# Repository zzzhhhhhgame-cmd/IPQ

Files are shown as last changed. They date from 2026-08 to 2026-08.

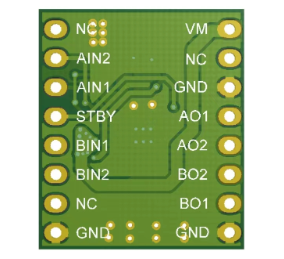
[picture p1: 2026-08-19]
参考资料/D2-1-2F（未焊接）/引脚图.png

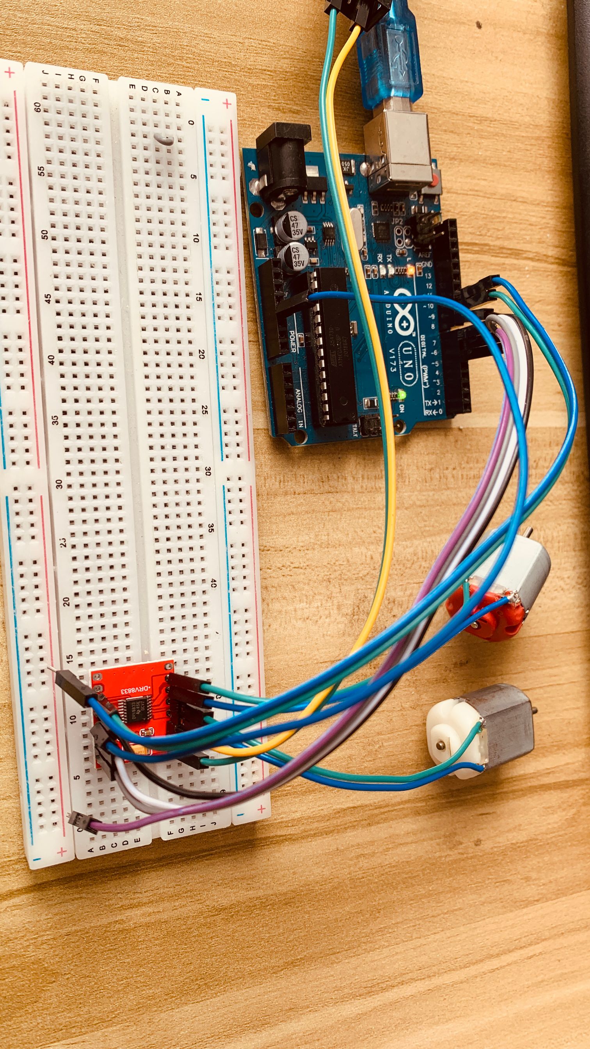
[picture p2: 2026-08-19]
参考资料/D2-1-2F（未焊接）/实物图.png

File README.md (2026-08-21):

# IPQ 项目仓库

**研究课题**：在自建双电机小车上，对比 S 曲线开环运动规划与 PID 闭环控制在**电能消耗**、**任务时间**上的差异，并量化 PID 反馈对**双轮转速差**（直线跑偏）的抑制能力——这是开环控制无法解决的问题。

**硬件平台**：ESP32 DevKit V1 + DRV8833 电机驱动 + JGB37-520B 编码器电机 ×2 + INA226 电压/电流传感器 + IMU（MPU6050 / LSM6DS3 自动识别）+ microSD 模块。

---

## 目录结构

```
IPQ/
├── 工程文件/          # 小车工程：代码、接线、物料清单
│   ├── ipq_robot_test/        # 全系统联合测试程序（.ino + 操作说明）
│   ├── ipq_pid_speed/         # 双轮 PID 速度控制程序（.ino + 教程/说明 + 串口日志）
│   ├── i2c_identify/          # I2C 器件识别小工具（确认 IMU 实际芯片型号）
│   ├── wiring.html            # 接线总图（网页版）
│   ├── wiring-checklist.html  # 逐线接线检查清单（v3.1，与固件引脚一一对应）
│   ├── bom.html               # 物料清单（BOM）
│   └── pcb/                   # 面包板→PCB 载板工程（Gerber/原理图/装配说明，见 pcb/README.md）
│
├── 答辩/              # 项目申请书（Project Proposal Form）及答案草稿
│   ├── PPF draft answers.md              # PPF 各栏目的答案草稿（Markdown，便于复制修改）
│   ├── project proposal form - IPQ draft.docx  # 申请书 Word 草稿（与上一文件内容一致）
│   └── project proposal form(1).docx           # 申请书 Word 版本
│
├── 参考资料/          # 整理性资料：硬件资料、教材、论文总结、实验提取报告及其生成脚本
│   ├── D2-1-2F（未焊接）/               # DRV8833 驱动板产品资料（接线说明、引脚图、真值表、芯片手册、uno 示例代码）
│   ├── PID Controllers (Åström & Hägglund).pdf  # PID 控制经典教材（理论背景）
│   ├── summaries/                    # 5 篇论文的中文总结 PDF（自整理）
│   ├── extracted/                    # 5 篇论文的全文纯文本提取（工作数据）
│   ├── Experiment_Extraction_Report.pdf  # 5 篇论文的实验设计提取报告（自整理）
│   ├── gen_summaries.py              # 生成 summaries/ 的脚本（ReportLab）
│   ├── gen_experiments.py            # 生成 Experiment_Extraction_Report.pdf 的脚本
│   └── _exp_content.py               # 提取报告的正文数据（被 gen_experiments.py 加载）
│
├── 参考文献/          # 研究引用的原始文献
│   └── paper/         # 5 篇原始论文 PDF（括号内为对应总结编号）
│       ├── Control-BLDC-Motor-Speed-using-PID-Controller.pdf            # Mahmud et al., 2020（01）
│       ├── Design_and_implementation_speed_control.pdf                 # Hammoodi et al., 2020（02）
│       ├── FA01_1.pdf                                                  # Meckl et al., 1998（03）
│       ├── Speed_Control_of_DC_Motor_Using_Fuzzy_PI.pdf                # Bansal et al., 2013（04）
│       └── nguyen-et-al-2008-on-algorithms-for-planning-s-curve-motion-profiles.pdf  # Nguyen et al., 2008（05）
│
├── .gitignore
└── .gitattributes
```

---

## 分类说明

### 1. 工程文件（及其说明）

小车本体相关的全部工程内容。三个 Arduino/ESP32 工程：

| 工程 | 用途 |
|---|---|
| `ipq_robot_test` | 全系统联合测试：双电机 + 编码器 + IMU + INA226 + microSD，遥测 10 Hz 记录 |
| `ipq_pid_speed` | 双轮独立 PID 速度控制（含抗积分饱和），附实验教程、使用说明和串口日志（`serial_logger.py` 采集） |
| `i2c_identify` | I2C 总线扫描，识别传感器板上实际焊接的芯片型号 |

接线与物料文档：`wiring*.html` 与 `bom.html`，其中 `wiring-checklist.html` v3.1 与固件引脚定义逐线对应。`pcb/` 为面包板方案的 PCB 载板工程（Python 生成 Gerber，可直接在嘉立创下单；含原理图、预览与装配说明）。

### 2. 答辩

IPQ 项目申请书（Project Proposal Form）的填写材料。`PPF draft answers.md` 是各栏目答案的 Markdown 版，便于编辑和复制；两份 `.docx` 为提交用的 Word 版本。**待填写**：Candidate number（大考 4 位考号）、Candidate name（护照拼音名）。

### 3. 参考资料

围绕文献与硬件做的整理性材料：

- **硬件资料**（`D2-1-2F（未焊接）/`）：所用 DRV8833 驱动板的产品资料（接线说明、引脚图、真值表、芯片手册、uno 示例代码）。
- **教材**：Åström & Hägglund《PID Controllers》，PID 整定理论的背景阅读。
- **论文总结**（`summaries/`）：5 篇核心文献的中文总结 PDF。
- **实验提取报告**（`Experiment_Extraction_Report.pdf`）：从 5 篇论文中提取的自变量/因变量/控制变量等实验设计要素，用于设计自己的实验方案。
- **生成脚本**：`gen_summaries.py` 与 `gen_experiments.py`（加载 `_exp_content.py`）可用 ReportLab 重新生成上述 PDF；`extracted/` 为论文纯文本提取结果。

### 4. 参考文献

研究引用的 5 篇原始论文（`paper/`），编号与 `参考资料/summaries/` 一一对应。申请书中引用的完整文献还包括 Åström & Hägglund 教材（见 `参考资料/`）。

---

## 文档再生成方法

两个生成脚本已改为相对路径，可在任意系统上运行（依赖 `reportlab`；中文字体自动在 Windows / macOS 系统字体中查找，也可将 Noto Sans SC 字体放在脚本同目录）：

```bash
cd 参考资料
pip install reportlab
python gen_summaries.py     # 重新生成 summaries/ 下 5 份总结 PDF
python gen_experiments.py   # 重新生成 Experiment_Extraction_Report.pdf
```

## 工作约定

- 修改任何文件后提交并推送到 `origin/main`。

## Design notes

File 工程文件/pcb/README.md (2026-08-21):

# IPQ 小车模块载板（面包板 → PCB）

把 `wiring v3.3` 的 **42 根杜邦线变成一块 PCB**。板上提供 ESP32 / DRV8833 / GY-521 的排母插座和电池、电机、编码器接线端子；INA226、MP1584、microSD 三个"丝印版本多变"的模块通过标牌插座 + 杜邦线/短线对接（**任意版本都兼容，不会插错**）。固件（`ipq_robot_test` / `ipq_pid_speed`）引脚无需任何改动。

- 板子：**95 × 80 mm，2 层，1.6mm**，底层整板 GND 铺铜（带热焊盘）
- 电气上与面包板版完全一致：逻辑电源在 INA226 之前分支（INA226 只测电机能耗）、STBY 接 3V3、INA226 串联在 电池+ → VM 之间

## 文件说明

| 文件 | 用途 |
|---|---|
| `out/IPQ_CARRIER_V1_gerber.zip` | **嘉立创直接上传的制造文件**（Gerber + 钻孔） |
| `out/schematic.svg` | 电路原理图（浏览器打开） |
| `out/preview_top.png` / `out/preview_bottom.png` | 顶层 / 底层铜预览图 |
| `out/report.txt` | 自动间距检查（DRC-lite）报告，0 错误 |
| `gen_board.py` + `gerblib.py` | 生成器源码（改布局后 `python3 gen_board.py` 重新生成一切） |
| `check_connect.py` | 网络连通性审计（每条网络单一连通分量） |
| `gen_schematic.py` | 原理图生成器 |

## 嘉立创下单步骤

1. 打开 [jlc.com](https://www.jlc.com) → PCB 制造 → **上传 PCB 制造文件**，选 `out/IPQ_CARRIER_V1_gerber.zip`。
2. 参数确认（其余默认）：
   - 层数 **2**，板厚 **1.6mm**，数量 **5**（经济板约 ¥2–10 + 运费）
   - 颜色任意（绿色最便宜/最快），表面处理默认"喷锡（有铅）"，阻焊覆盖过孔：是
   - 系统识别的最小线宽/间距应 ≥ 0.4/0.2mm（本板最小值，满足经济板工艺）
3. 预览核对：上传后在线预览应与 `preview_top.png` 一致（顶层丝印 "IPQ-2026 ROBOT CARRIER v1.0"）。

## ⚠ 下单前必做：两个尺寸核对（拿尺子量你手上的模块）

插座位置按以下尺寸设计，若与你手上的模块不符，**先改 `gen_board.py` 顶部常量再重新生成**：

| 模块 | 设计采用尺寸 | 怎么量 |
|---|---|---|
| ESP32 DevKit V1 30P | 两排孔中心距 **22.86mm**（0.9 英寸，行业标准） | 量板上两排焊孔中心距离 |
| DRV8833 (D2-1-2F) | 2 列 × 8 孔、列内间距 2.54、**两列中心距 10.16mm** | 对照模块丝印逐孔核对：左列 NC·AIN2·AIN1·STBY·BIN1·BIN2·NC·GND，右列 VM·NC·GND·AO1·AO2·BO2·BO1·GND |
| GY-521 | 1×8 孔 @2.54 | 通用 |

> 若 DRV8833 实测列距不是 10.16mm（比如 12.7），只需改 `gen_board.py` 中 `DX_R = 62.16` 一行（= 左列 x + 实测列距），重跑生成器即可，布线已按 2.54 网格自适应大部分调整。

## 载板装配清单（PCB 之外要买的插件）

| 器件 | 数量 | 规格 / 搜索关键词 |
|---|---|---|
| 排母 1×15P 2.54mm | 2 | ESP32 插座（可用 2×15 整条剪开） |
| 排母 1×8P 2.54mm | 3 | DRV8833 ×2 + GY-521 ×1 |
| 排母 1×6P 2.54mm | 1 | microSD 插座 |
| 排母 1×4P 2.54mm | 2 | MP1584 / INA226 逻辑插座 |
| 排母 1×2P 2.54mm | 1 | J9 逻辑电源跳线（配跳线帽） |
| 端子 KF301-2P 5.08mm | 5 | 电池 ×1、电机 ×2、INA226 动力 ×2（用 1×4P 剪或买 2P） |
| 端子 KF3500-4P 3.5mm | 2 | 编码器（左右） |
| 电解电容 100µF/16V | 1 | C1（VM 滤波，5mm 脚距） |
| 瓷片电容 104 (100nF) | 1 | C2（2.54 脚距） |
| 跳线帽 2.54mm | 2 | J9 电源 + JP1 SD-VCC 选择 |
| M3 螺丝/铜柱 | 4 | 固定到车上 |

安装提示：排母建议选 8.5mm 高（普通 8.5mm 即可，模块插入后芯片面朝上）。

## 装配顺序（建议）

1. 焊 C2（瓷片，最矮）→ C1（电解，**长脚为正极朝 VM 一侧**，板上丝印有 + 标记）。
2. 焊全部排母、端子、J9/J P1 跳线座。端子焊缝开口朝板外（插线方向）。
3. 插上 ESP32（USB 朝板上边缘，对照丝印 "USB THIS END"）。
4. **DRV8833 模块先自己焊好 2×8 排针**（模块丝印朝上时：左列对齐载板左列丝印 NC·AIN2·AIN1·STBY·…），再插入排母。
5. GY-521 直接插入 1×8 排母（板上丝印 VCC·GND·SCL·SDA·…）。
6. 三根杜邦线对接 MP1584（**按丝印一一对应**：IN+/IN−/OUT+/OUT−）；四根对接 INA226 逻辑侧（VCC/GND/SDA/SCL）。
7. 动力路径两根粗线（≥20AWG）：
   - `J8 BAT+` 端子同时压接「电池盒红线」+「去 MP1584 的分接线」（与面包板方式 A 相同）
   - `J6 V+IN` → INA226 模块 **VIN+** 端子；INA226 模块 **VIN−** → `J6 V-OUT`
8. microSD 六根杜邦线按丝印对接；JP1 按模块版本把中间焊盘与 3V3 或 5V 焊锡桥接。
9. 电机线接入 J13/J14（M+/M−），编码器线接入 J2/J3（板上丝印 A·B·GND·3V3）。

## 上电检查（沿用面包板版清单）

- 万用表量 J8 空载：BAT+ 对 GND 应不通；接电池后 VM 端子（J6 V-OUT 侧）对 GND ≈ 电池电压（经 INA226）
- J9 插跳线帽 = 逻辑上电；拔掉 = 逻辑断电（拔电池才是完全断电）
- 先不接电机，I²C 扫描应出 **0x40 (INA226)** 和 **0x68 (MPU6050)**
- 低 PWM（30%）试转，方向不对就对调 AO1/AO2（或 BO1/BO2）两根电机线
- 烧录失败：拔下 microSD 模块再烧（GPIO2 是启动脚，与面包板版相同）

## 已知取舍

- microSD / INA226 / MP1584 采用杜邦线对接而非插座直插：这三个模块市面上丝印顺序五花八门，直插底板一旦做错就整板报废；标牌对接对任意版本零风险，也便于烧录时拔 SD。
- 逻辑电源开关（J9 跳线）只控制 MP1584 输入（≤0.5A）；电机主回路不串开关（小开关扛不住堵转电流），完全断电请拔电池端子。

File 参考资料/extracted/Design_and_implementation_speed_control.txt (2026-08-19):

International Journal of Power Electronics and Drive System (IJPEDS) 
Vol. 11, No. 1, March 2020, pp. 127~134 
ISSN: 2088-8694, DOI: 10.11591/ijpeds.v11.i1.pp127-134 
     127 

Journal homepage: http://ijpeds.iaescore.com 
Design and implementation speed control system of DC Motor 
based on PID control and Matlab Simulink 

Salman Jasim Hammoodi1, Kareem Sayegh Flayyih2, Ahmed Refaat Hamad3 
1 Department of Machines Technology, Middle Technical University, Iraq 
2 Department of Electronic Technology, Southern technical University, Iraq 
3 Department of Electrical Technology, Middle Technical University, Iraq 

Article Info 
 
ABSTRACT 
Article history: 
Received May 9, 2019 
Revised Jul 22, 2019 
Accepted Aug 4, 2019 

In this paper, we first write a description of the operation of DC motors 
taking into account which parameters the speed depends on thereof. The PID 
(Proportional-Integral-Derivative) controllers are then briefly described, and 
then applied to the motor speed control already described, that is, as an 
electronic controller (PID), which is often referred to as a DC motor. The 
closed loop speed control of a Brush DC motor is developed applying the 
well-known PID control algorithm. The objective of this work is to designed 
and simulate a new control system to keep the speed of the DC motor 
constant before variations of the load (disturbances), automatically 
depending to the PID controller. The system was designed and 
implementation by using MATLAB/SIMULINK and DC motor. 
Keywords: 
DC Motor 
MATLAB/SIMULIK 
PID 
PWM 
Speed control 
This is an open access article under the CC BY-SA license. 
 
Corresponding Author: 
Salman Hammoodi,  
Department of Machines Technology, 
Institute of Technology Baghdad, Middle Technical University, 
Al-Za’franiya, 10074 Baghdad, Iraq 
Email: salmanhammoodi66@gmail.com 

1. 
INTRODUCTION 
At present, most of the motors in the industry are handled directly from the electrical distribution 
lines, whether they are DC or AC motors. Because of this, the behaviour of the motor depends on the nature 
of the load coupled to the axis of the machine [1-5]. In the case of a light load the motor develops a relatively 
high speed and a low torque because it is the load requirement. On the contrary, if a heavy or difficult to 
move load is available, the motor will move at a lower speed and deliver more torque as a higher load 
demands it [4-9]. 
As can be seen by directly connecting the motor to the AC or DC electrical network, its behaviour is 
defined and it will remain unchanged for a certain fixed voltage in the power supply line. However, in a large 
part of the industrial sector, there are processes in which the management of the operating characteristics of 
said machines is required, which is why parameter control devices such as speed and frequency variations are 
used. In the case of AC motors, these devices are commonly used and have a relatively low cost, however, 
when working with DC motors the variable speed drives have an excessively high cost which makes them 
little accessible to many industries that require its use [6-12]. 
In this paper to design and implementation speed control system of DC Motor based on PID control 
and Matlab Simulink, the motor is divided into two main parts the electrical part of the armature and the 
mechanical part [11, 12]. The armature is modelled as a circuit with resistance R connected in series to a 
conductor L, a source of voltage V and constant Kb of force against electromotive in the armature. The 
      
  
 
       ISSN: 2088-8694 
 Int J Pow Elec & Dri Syst Vol. 11, No. 1, Mar 2020 :  127 – 134 
128
mechanical part of the motor is the rotor which, when in motion, has a moment of inertia J, a Torque T, a 
viscous friction coefficient b, a position θ and an angular velocity bθ = ω [4,7,10,11-12]. 
The PID controller is responsible for correcting the error it receives from the difference of the input 
signal and the output signal of the tachometer, the corrected error enters an amplification stage before 
entering the plant. In this paper the development of a speed and direction motor for an autonomous race robot 
is presented. Both controls use the PID control algorithm [13, 15-20]. 
The paper aims to provide a solution to the difficult access that economic conditions have for these 
automation technologies, developing an own speed control system for any DC motor that requires it, 
economically viable and applicable to any type of machine, of easy use and implementation in all types of 
industrial processes[19-25]. 

2. 
THE BASICS OF DC MOTORS 
The history of the development of the construction of electric machines began in 1831 with the 
discovery of Faraday's law until the middle of the eighth decade of the last century. The DC motors are 
machines that convert electrical energy into mechanical energy, causing a rotary movement. There were 
several reasons for the prolonged popularity of dc motors. One was that DC power systems are common even 
in cars, trucks and airplanes. When a vehicle has a DC power system, it makes sense to use DC motors. DC 
motors were also applied when wide variations in speed were required. Before the widespread use of 
electronic power rectifier inverters, dc motors were not matched in speed control applications. Even if there 
were no dc power source, the solid-state rectifiers and the trimmer circuits were used to create the necessary 
power; dc motors were used to provide the desired speed control (induction motors with groups of solid-state 
controllers are now preferred for most speed control applications.) However, there are still applications where 
DC motors)[6-9]. 
The dc motors are driven by a dc power source. Unless otherwise specified, it is assumed that the 
input voltage is constant, since this assumption simplifies the analysis of the motors and the comparison 
between the different types of them. There are five types of general purpose DC motors: 
 
Independent excitation direct current motor. 
 
Direct current motor in derivation. 
 
Permanent magnet direct current motor. 
 
Direct current motor in series. 
 
Composite direct current motor. 
The Figure 1 show the full equivalent circuit of the dc motor. The equivalent circuit in Figure 1 is 
similar to the generator circuit only the current directions are different. The operation equations are, (1) is 
present the Armature voltage equation [11-12].  

Figure 1. Full equivalent circuit of DC motor 

𝑉ௗ௖ൌ𝐸௔௠൅𝐼௔௠𝑅௔൅𝑉௕௥௨௦௛ 
(1) 
 
The induced motor voltage and motor speed vs angular frequency of the motor is present in (2). The 
combination is present in (3) and the output power and torque are present in (4). 
 
𝐸௔௠ൌ𝐾௠𝐼௙𝜔 
 
𝜔ൌ2𝜋𝑛௠ 
(2) 
𝐾௠𝐼௙𝜔ൌ𝐸௔௠ൌ𝑉ௗ௖െ𝐼௔௠𝑅௠ 
(3) 
𝑃௢௨௧ൌ𝐸௔௠𝐼௔௠  
Int J Pow Elec & Dri Syst 
ISSN: 2088-8694 
 
 
Design and implementation speed control system of DC Motor based on PID ... (Salman Jasim Hammoodi) 
129
𝑇ൌ
௉೚ೠ೟
ఠൌ𝐾௠𝐼௔௠𝐼௙ 
(4) 

3. 
THE EXPLANATION OF PID CONTROLLER SYSTEM 
3.1. The control systems 
Automatic control is of vital importance in the world of engineering. In addition to being essential in 
robotic systems or modern manufacturing processes, among others applications, has become essential in 
industrial operations such as pressure control, temperature, humidity and viscosity, and flow in the 
processing industries. Figure 2 shows a generic block diagram of a control system, in the Laplace domain. 

Figure 2. The block diagram of a control system 

Typically, the feedback contains a sensor or transducer element that measures a physical parameter, 
such as speed or temperature, and converts it into a voltage or current. 
The basic function of a controller is to compare the real value of the output of a plant c(t), with the 
reference input r(t) (desired value), determine the error e(t), and produce a control signal that will reduce the 
error to a value close to zero. 
Figure 3 present the specifications for a control problem are often given in the time domain,  
and usually include a certain transient response and an error in state stationary, for a specific entry as is 
usually a step. 

Figure 3. The specifications for a control problem 

One way to achieve this is by placing a transfer driver Gc (s), in the control loop, as shown in the 
Figure 3. The error signal E (s) is the input to the controller, and U (s) is the output of the same and at the 
same time the input to the plant, and the purpose of the controller is to make the output of the system follow 
the input. In Figure 4 we observe the different types of response according to the controller that is used. 

  
 
       ISSN: 2088-8694 
 Int J Pow Elec & Dri Syst Vol. 11, No. 1, Mar 2020 :  127 – 134 
130

Figure 4. Response to the step of a closed-loop feedback system given by: (a) Controller P (b) Controller PD 
(c) Controller PID 

3.2. The PID controllers method 
error is changing with respect to time. In this way, the controller can estimate future values of the 
error signal and compensate accordingly. It should be taken into account that even if the error is constant and 
the derivative term does not contribute, if it is variant in time this term can be used to reduce the offset called 
steady-state error. Another problem associated with the PD is that it works like a high-pass filter. Therefore, 
the PD controller amplifies the high frequency noise, which reduces the stability of the total system. 
To eliminate the steady state error, an integral term is added. That term it gives the PID controller 
the ability to remember the past, also allowing an output non-zero for a null entry. So this controller allows to 
have a status error stationary equal to zero. In return, the integrator adds a pole in the function of closed loop, 
with which the stability of the system declines. From the above, the PID is an excellent controller. The 
transfer function is given in (5)[12-18]: 
 
𝐺௖ሺ𝑠ሻൌ𝐾௣൅𝐾ௗ. 𝑆൅
௄೔
ௌ 
(5) 
 
It should be clarified that if a mathematical model of the plant can be deduced, it is possible apply 
several techniques to determine the controller parameters, which comply with the transient and steady state 
specifications of the closed loop system. However, if the plant is so complicated that you cannot easily obtain 
your mathematical model, the analytical design model of the PID controller is possible. Then you have to 
resort to experimental procedures for the design of this type of controller. The process of select the 
parameters of the controller so that it meets the specifications of operation is known as tuning or tuning the 
controller. Ziegler and Nichols suggested rules for tuning PID controllers, that is, setting the values of Kp, 
Kd and Ki[11,16]. 
 
3.3. Types of PID controllers  
for PIDs The transfer functions for the different types of PID drivers are[20-25]: 
a. 
PID not interacting or ideal form : is present in (6). 
 
𝐺௖ሺ𝑝ሻൌ𝐾௖. ቀ1 ൅
ଵ
்೔൅
ଵା்೏.௣
ଵାఈ.்೏.௣ቁ 
(6) 
 
b. 
Interactive PID or series form : is present in (7). 
 
𝐺௖. ሺ𝑝ሻൌ𝐾௖. ቀ1 ൅
ଵ
௄೔.௣ቁ. ቀ
ଵା்೏
ଵାఈ.்೏.௣ቁ 
(7) 
 
c. 
PID parallel form : is present in (8). 
 
Int J Pow Elec & Dri Syst 
ISSN: 2088-8694 
 
 
Design and implementation speed control system of DC Motor based on PID ... (Salman Jasim Hammoodi) 
131
𝐺௖ሺ𝑝ሻൌ𝐾௣൅
௄೔
௣൅
௄೏.௣
ଵାఈ.்೏.௣ 
(8) 
 
d. 
PID industrial form : is present in (9). 
 
𝑢ሺ𝑡ሻൌ𝐾௖. ቀ1 ൅
ଵ
்೏.௣ቁ. ቀ𝑟ሺ𝑡ሻെ
ଵା்೏.௣
ଵାఈ.்೏.௣. 𝑦ሺ𝑡ሻቁ 
(9) 

4. 
SIMULATION RESULTS AND DESCTIONS 
Figure 5 shows the final MATLAB/SIMULINK speed control circuit separately excited dc motor 
using chopper transistor circuit. MATLAB/SIMULINK toolbox is used in this paper to model the full 
system, it consists of DC motor fed by a DC source voltage through a chopper transistor circuit. A single of 
GTO-1 thyristor with its full control circuit and a free wheeling diode form the chopper circuit. The GTO-1 is 
a switch modeled. The switch block model has three terminals: the middle terminal is a controls which of the 
two other terminals is routed to the output. The control input signal is one, DC V is leading to the output 
voltage, on the other hand, the control input singals is zero, a zero will be leading to the output. 

Figure 5. The final simulation circuit of the speed control motor based on PID control 

The DC motor drives system with a mechanical load characterized by inertia (J), friction coefficient 
(B), and torq of the load (TL). The control circuit of the DC motor system consists of a speed control loop. A 
proportional-integral-Drivetive (PID) controlled the speed of the control loop senses the actual speed of the 
DC motor, and compares the mesurring speed with the reference speed (constant value) to determine the 
reference armature current will be required by the DC motor. One may notice that any difference in actual 
speed is a measure of the current of the motor required by the engine. 
The simulation results of the full system are present on Figure 6 to Figure 9. Figure 6 present the 
simulation results of rated speed (wr) related to the reference speed, in this figure we can see the fast 
response of the PID control system of the system.  

  
 
       ISSN: 2088-8694 
 Int J Pow Elec & Dri Syst Vol. 11, No. 1, Mar 2020 :  127 – 134 
132

Figure 6. Simulation results of rated speed (wr) related to the reference speed 

The load torque (TL) in Figure 7 and the armature current (A) of the DC motoe is presented in the 
Figure 8 of the DC motor is presented the same fast response of the PID control system. Finaly the PWM 
signals of the thyristor (GTO-1) is presented in the Figure 9.  
 
Note: The parameter of the PID are (P=4, I=0.01 and D=0.5. 

Figure 7. The load torque (TL) of the DC motoe 
Int J Pow Elec & Dri Syst 
ISSN: 2088-8694 
 
 
Design and implementation speed control system of DC Motor based on PID ... (Salman Jasim Hammoodi) 
133

Figure 8. The armature current (A) of the DC motoe 

Figure 9. The PWM signals of the thyristor (GTO-1) 

5. 
CONCLUSION 
The first point discussed in this work was the description of the operation of a DC motor, where the 
different aspects related to its operation were analysed, and the parameters that influence the speed control of 
them. Then, made the operation of the PID controllers system, and their application to the control of the 
speed of a DC motor. It is important to consider here that the effect on the dynamic behaviour of a control 
loop is directly related to the type of controller used, PID in our specific case, and its operation, either as a 
servomechanism or as a regulatory system. But it must also be taken into account that the equations used by 
the manufacturers to carry out their PID controllers are not all the same. 
The differences that exist between the equations used by the manufacturers to represent the PID 
algorithm in their loop controllers, direct digital control programs and other equipment, make it indispensable 
to know in order to be able to calculate the required parameters thereof in an appropriate manner and achieve 
the desired dynamic behaviour of the control loop. The foregoing is fundamentally important when replacing 
one controller with another, especially if the new one is from another manufacturer. 
The results that have been presented and the methodology that has been proposed represent an 
important contribution in the field of experimental modelling of systems for obtaining models of the 
dynamics of unknown systems. 
      
  
 
       ISSN: 2088-8694 
 Int J Pow Elec & Dri Syst Vol. 11, No. 1, Mar 2020 :  127 – 134 
134
REFERENCES 
[1] 
A. J. Humaidi and I. Kasim Ibraheem, “Speed Control of Permanent Magnet DC Motor with Friction and 
Measurement Noise Using Novel Nonlinear Extended State Observer-Based Anti-Disturbance Control,” Energies, 
vol. 12, no. 9, p. 1651, 2019. 
[2] 
X. Yao, J. Zhao, G. Lu, H. Lin, and J. Wang, “Commutation Error Compensation Strategy for Sensorless Brushless 
DC Motors,” Energies, vol. 12, no. 2, p. 203, 2019. 
[3] 
J. Hong, S. Wang, Y. Sun, and H. Cao, “An effective method with copper ring for vibration reduction in permanent 
magnet brush DC motors,” IEEE Trans. Magn., vol. 54, no. 11, pp. 1–5, 2018. 
[4] 
L. Li and D. Jia, “Research on Air conditioning system of subway station based on fuzzy PID control,” Proc. - 
2017 4th Int. Conf. Inf. Sci. Control Eng. ICISCE 2017, pp. 1131–1134, 2017. 
[5] 
E. Guerrero, J. Linares, E. Guzmán, H. Sira, G. Guerrero, and A. Martínez, “DC Motor Speed Control through 
Parallel DC/DC Buck Converters,” IEEE Lat. Am. Trans., vol. 15, no. 5, 2017. 
[6] 
P. Alaeinovin and J. Jatskevich, “Filtering of hall-sensor signals for improved operation of brushless DC motors,” 
IEEE Trans. Energy Convers., vol. 27, no. 2, pp. 547–549, 2012. 
[7] 
X. Changbo, L. Congcong, B. Zhenfu, and Z. Chengjin, “PID self-tuning immune fuzzy control of steam 
temperature control system in fossil-fired power plant,” Proc. World Congr. Intell. Control Autom., vol. 1,  
pp. 3973–3977, 2006. 
[8] 
N. Kasa and H. Watanabe, “A mechanical sensorless control system for salient-pole brushless DC motor with 
autocalibration of estimated position angles,” IEEE Trans. Ind. Electron., vol. 47, no. 2, pp. 389–395, 2000. 
[9] 
Y. Mandel and G. Weiss, “Reduction of torque ripple in brushless DC motor drives,” IFAC Proc., vol. 6, no. 1,  
pp. 84–89, 2009. 
[10] I. Alhamrouni, M. A. Hairullah, N. S. Omar, M. Salem, A. Jusoh, and T. Sutikno, “Modelling and design of PID 
controller for voltage control of AC hybrid micro-grid,” International Journal of Power Electronics and Drive 
System (IJPEDS), vol. 10, no. 1, pp. 151–159, 2019. 
[11] M. A. Ibrahim, A. K. Mahmood, and N. S. Sultan, “Optimal PID controller of a brushless DC motor using  
genetic algorithm,” International Journal of Power Electronics and Drive System (IJPEDS), vol. 10, no. 2,  
pp. 822–830, 2019. 
[12] N. N. Baharudin and S. M. Ayob, “Brushless DC motor speed control using single input fuzzy PI controller,” 
International Journal of Power Electronics and Drive System (IJPEDS), vol. 9, no. 4, pp. 1952–1966, 2018. 
[13] Y. Tarmizi, A. Jidin, K. A. Karim, and T. Sutikno, “A simple constant switching frequency of direct torque control 
of brushless DC motor,” International Journal of Power Electronics and Drive System (IJPEDS), vol. 10, no. 1,  
pp. 10–18, 2019. 
[14] M. Dasari, A. Srinivasula Reddy, and M. Vijaya Kumar, “GA-ANFIS PID compensated model reference adaptive 
control for BLDC motor,” International Journal of Power Electronics and Drive System (IJPEDS), vol. 10, no. 1, 
pp. 265–276, 2019. 
[15] Mohannad Jabbar Mnati, “Position Control for flexible Joint Maipulator using Artificaial Neutral Network”, 
University of Technology, Department Of Electrical & Electrionics Engineering, Baghdad, Iraq, 2005. 
[16] P. Bhaskara Prasad, M. Padma Lalitha, and B. Sarvesh, “Fractional order PID controlled cascaded re-boost seven 
level inverter fed induction motor system with enhanced response,” International Journal of Power Electronics and 
Drive System (IJPEDS), vol. 9, no. 4, pp. 1784–1791, 2018. 
[17] R. Meena Devi and L. Premalatha, “Soft computing technique of bridgeless SEPIC converter for PMBLDC motor 
drive,” International Journal of Power Electronics and Drive System (IJPEDS), vol. 9, no. 4, pp. 1503–1509, 2018. 
[18] A. Rincón, F. Angulo, and F. Hoyos, “Controlling a DC Motor through Lypaunov-like Functions and SAB 
Technique,” International Journal of Electrical and Computer Engineering (IJECE), vol. 8, no. 4, p. 2180, 2019. 
[19] M. J. Mnati, D. V. Bozalakov, and A. Van den Bossche, “PID Control of a Three Phase Photovoltaic Inverter Tied 
to a Grid Based on a 120-Degree Bus Clamp PWM,” IFAC-PapersOnLine, vol. 51, no. 4, pp. 388–393, 2018.  
[20] A. Faruq, M. F. N. Shah, and S. S. Abdullah, “Multi-objective optimization of PID controller using pareto-based 
surrogate modeling algorithm for MIMO evaporator system,” International Journal of Electrical and Computer 
Engineering (IJECE), vol. 8, no. 1, pp. 556–565, 2018. 
[21] A. Prayitno, V. Indrawati, and I. I. Trusulaw, “Fuzzy gain scheduling PID control for position of the AR. Drone,” 
International Journal of Electrical and Computer Engineering (IJECE), vol. 8, no. 4, pp. 1939–1946, 2018. 
[22] H. Sun, M. J. Mnati, M. Nabil Ibrahim, and A. Van Den Bossche, “A Tuning Method for the Derivative Filter in 
PID Controller with Delay Time,” Proc. 2018 9th Int. Conf. Mech. Aerosp. Eng. ICMAE 2018, pp. 574–578, 2018. 
[23] H. Sun, M. N. Ibrahim, M. Jabbar Mnati, and A. Van Den Bossche, “A Tuning Method for PI Controller for an 
Integrating System with Time Delay,” Proc. 2018 9th Int. Conf. Mech. Aerosp. Eng. ICMAE 2018, pp. 410–414, 
2018. 
[24] M. Yaich and M. Ghariani, “A novel technique for tuning PI-controller in switched reluctance motor drive for 
transportation systems,” International Journal of Electrical and Computer Engineering (IJECE), vol. 8, no. 6, pp. 
4272–4281, 2018.  
[25] M. A. Shamseldin, M. Sallam, A. M. Bassiuny, and A. M. Abdel Ghany, “A novel self-tuning fractional order PID 
control based on optimal model reference adaptive system,” International Journal of Power Electronics and Drive 
System (IJPEDS), vol. 10, no. 1, pp. 230–241, 2018.

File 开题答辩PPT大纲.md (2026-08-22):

# 开题答辩 PPT 大纲与讲稿（7–8 分钟，纯英文）

> 配套文件：`project proposal form - IPQ draft.docx` / `PPF draft answers.md`
> **成品幻灯片：`IPQ开题答辩.pptx`（12 页，16:9）**——本大纲即其逐页内容与讲稿。
> 用法：每页给出【幻灯片上放什么】（英文要点）和【讲什么】（英文讲稿，含时长）。
> 讲稿全文约 1150 词 ≈ 7 分半（140 词/分钟）。幻灯片只放要点，句子留给嘴说。
> 待替换项：第 1 页 `[Your Name]`；第 3、9 页的图片占位框（小车照片、CSV 曲线截图）。

## 总览

| # | 幻灯片 | 部分 | 时长 |
|---|---|---|---|
| 1 | Title | — | 0:20 |
| 2 | Outline | — | 0:15 |
| 3 | The Problem I Met | 1 背景与动机 | 0:50 |
| 4 | Two Ways to Command a Motor | 1 背景与动机 | 1:00 |
| 5 | Research Gap & Research Question | 1 背景与动机 | 0:45 |
| 6 | Test Platform & Measurement | 2 实验设计 | 0:45 |
| 7 | Variables & Experimental Protocol | 2 实验设计 | 1:00 |
| 8 | Metrics & Hypotheses | 2 实验设计 | 0:45 |
| 9 | Feasibility: Platform & Data Pipeline | 3 可行性 | 0:40 |
| 10 | Feasibility: Skills, Risks & Backups | 3 可行性 | 0:40 |
| 11 | Timeline (Aug 2026 – Apr 2027) | 4 时间规划 | 0:45 |
| 12 | Summary & Expected Contribution | — | 0:30 |

**合计 ≈ 7:35**（留 20–30 秒缓冲）

---

## Slide 1 — Title（0:20）

**幻灯片内容：**
- S-curve vs. PID: Energy, Time and Differential Suppression for a Two-Motor Robot Car
- 一行小字放研究问题缩写版：*Which control strategy moves my robot car faster and cheaper — and which one keeps it straight?*
- Name / Centre CN213 Shanghai Guanghua College / IPQ 06/27 / Date

**讲稿：**
> Good afternoon everyone. My IPQ project compares two classic ways of controlling robot motors — S-curve motion profiling and PID feedback — on a robot car I built myself. I will measure which one completes a movement using less energy and less time, and which one can keep the car driving straight. Let me start with why I chose this topic.

## Slide 2 — Outline（0:15）

**幻灯片内容：**
- 1 Background & Motivation
- 2 Experimental Design
- 3 Feasibility
- 4 Timeline

**讲稿：**
> My presentation has four parts: the background and motivation, the experimental design, the feasibility, and my timeline from now until submission next April.

## Slide 3 — The Problem I Met（0:50）

**幻灯片内容：**
- Built a two-motor robot car (ESP32 + encoder motors)
- Observation 1: motors = biggest power consumer → battery drains fast, much energy wasted
- Observation 2: same PWM ⇒ two wheels differ by ~5% in speed → car drifts off a straight line
- Question raised: does *how* we command the motors change energy cost and accuracy?

**视觉建议：** 小车照片 + 两张遥测截图（rpmL vs rpmR 曲线分叉的那段）

**讲稿：**
> My interest came from building and testing this car. The first thing I noticed is that the motors are by far the biggest power consumers on the car — they drain the battery quickly, and a lot of the energy seems wasted rather than turned into motion. The second observation is on this plot: when both motors receive exactly the same PWM command, the two wheels still run at different speeds — about five percent apart, measured by the wheel encoders. That five percent comes from small manufacturing differences between the two motors, and it makes the car slowly curve off a straight line. So I started asking: does the way we command the motors change how much energy a movement costs, and how accurately the car moves?

## Slide 4 — Two Ways to Command a Motor（1:00）

**幻灯片内容：**
- S-curve motion profiling (open loop)
  - Speed follows a smooth, jerk-limited S-shaped reference
  - Standard in CNC / industrial robots; limits vibration & stress
  - (Nguyen et al. 2008; Meckl et al. 1998)
- PID feedback control (closed loop)
  - Controller corrects PWM continuously from measured speed error
  - Most widely used control algorithm in industry
  - (Åström & Hägglund; Mahmud et al. 2020; Hammoodi et al. 2020)
- Key structural difference: **open loop sees nothing; closed loop corrects**

**视觉建议：** 左右对比框图：左边 S 曲线→PWM→电机（无回箭头），右边编码器→PID→PWM→电机（有反馈回路）

**讲稿：**
> In the literature there are two mainstream answers to "how should a robot command its motors". The first is S-curve motion profiling. The speed reference follows a smooth, S-shaped curve that limits jerk. This is the standard in CNC machines and industrial robots, because it reduces vibration and mechanical stress. The second is PID feedback control, the most widely used control algorithm in industry: the controller reads the actual wheel speed from the encoders and continuously corrects the motor input to reduce the error. The structural difference is crucial: an S-curve profile is open-loop — however beautifully it is planned, it cannot see what the motors actually do. PID is closed-loop — it measures and corrects. In theory, feedback should be able to cancel the five-percent mismatch between my two motors, and no open-loop profile can.

## Slide 5 — Research Gap & Research Question（0:45）

**幻灯片内容：**
- Gap: most comparisons are **simulation-based, single idealised motor**
  - no mismatched-motor problem, no battery, no energy data
- Open questions on real, low-cost hardware:
  1. Which strategy completes a speed-change task with **less energy**?
  2. Which is **faster** to settle at the target speed?
  3. How much can **only PID** suppress the wheel-speed differential?
- **Research question** (highlight box):
  *How do S-curve open-loop profiling and PID closed-loop control compare in electrical energy and task time on a two-motor robot car, and to what extent can PID additionally suppress the wheel-speed difference that open-loop control cannot solve?*

**讲稿：**
> Here is the gap. Almost all the comparisons I found are simulations with a single idealised motor. In simulation the two motors are perfectly matched and power is free, so neither of my real problems exists. On real, battery-powered hardware, three questions stay open: which strategy uses less energy, which one settles faster, and how much wheel-speed differential can feedback alone remove? That gives my research question: I will compare S-curve and PID on the same car in energy and time, and quantify the differential suppression that only PID can provide.

## Slide 6 — Test Platform & Measurement（0:45）

**幻灯片内容：**
- ESP32 + 2 × JGB37-520B encoder motors (330 counts/rev) + DRV8833 driver
- Sensors: INA226 (voltage / current / power) · MPU6050 gyroscope (yaw rate)
- Firmware (already running): dual-wheel PID @100 ms, anti-windup, optional feed-forward
- Telemetry logged at 10 Hz to CSV: target, rpmL, rpmR, PWM, gyrZ, V, I, P
- To add: on-board **S-curve reference generator** for the open-loop mode

**视觉建议：** 平台框图或实物接线图 + CSV 列名截图

**讲稿：**
> This is my test platform, already built and working. An ESP32 controls two geared DC motors with encoders through a motor driver. Two sensing systems make the comparison measurable: an INA226 power sensor samples the electrical voltage, current and power, and a gyroscope measures the car's yaw rate — an independent check of whether the car is turning. The firmware already implements dual-wheel PID with anti-windup, and logs every variable — target speed, both wheel speeds, PWM, yaw rate, voltage, current, power — at ten hertz to a CSV file. The one thing I still need to add is an on-board S-curve reference generator, so the same car can run both strategies.

## Slide 7 — Variables & Experimental Protocol（1:00）

**幻灯片内容：**
- Independent variable: control strategy (S-curve open-loop vs. tuned PID)
- Dependent variables: **energy per task (J) · settling time (s)** · wheel-speed difference (rpmL−rpmR) · yaw rate
- Controlled: same car, surface, battery voltage window, target speeds, routine; ≥3 repeats per condition
- Experiments:
  - **A** Same speed-change task under both strategies → energy & time
  - **B** Step response → dynamics
  - **C** One-factor-at-a-time PID tuning (Kp, Ki, Kd, FF) → fair tuning
  - **D** Identical S-curve commands vs. per-wheel PID → differential suppression
  - **E** Robustness across target speeds (15 / 45 / 90 rpm)
- Extension: PID tracking an S-curve reference (combined strategy)

**讲稿：**
> The design is a controlled experiment. The independent variable is the control strategy. The main dependent variables are energy per movement and settling time, plus the wheel-speed difference and yaw rate. Everything else is controlled: the same car, the same surface, the same battery voltage window, and each condition is repeated at least three times. Five experiments: A runs the identical speed-change task under both strategies and compares energy and time. B measures the step response. C tunes the PID gains one factor at a time — this is important for fairness, so PID is properly tuned, not misrepresented. D is the unique-capability test: identical S-curve commands to both wheels versus independent PID on each wheel, measuring how much feedback removes the differential. E repeats the comparison at different target speeds. If time allows, I will also test a combined strategy: PID tracking an S-curve reference — the best of both worlds.

## Slide 8 — Metrics & Hypotheses（0:45）

**幻灯片内容：**
- Energy: integrate measured power over task time, E = Σ P·Δt (INA226 @10 Hz)
- Settling time: from command until speed stays within ±5% of target
- Analysis: mean ± SD over ≥3 repeats, plots in Python/Excel
- Hypotheses:
  - H1: PID settles **faster** but may overshoot; S-curve is smooth by construction
  - H2: energy outcome is genuinely **open** — that is why it must be measured
  - H3: PID drives rpmL−rpmR → ~0; open-loop S-curve leaves ~5% → drift

**讲稿：**
> How do I judge the winner? Energy is the time integral of the measured electrical power. Settling time runs from the command until the wheel speed stays within a five-percent band of the target. Three hypotheses. First, PID should settle faster, because an S-curve deliberately stretches the acceleration, but PID may overshoot. Second — and this is the honest part — I do not know which one uses less energy; that is exactly why the experiment is worth doing. Third, PID should push the wheel-speed difference close to zero, while the open-loop S-curve leaves the five-percent difference and the car keeps drifting. Any result here is informative.

## Slide 9 — Feasibility: Platform & Data Pipeline（0:40）

**幻灯片内容：**
- Hardware: **built, wired and running** — wiring checklist v3.3 tested
- Firmware: PID, telemetry, CSV logging **already produce data** (sample on the right)
- Remaining build work: one S-curve generator function (weeks, not months)
- Low cost, common components → easy to repair / replace
- Supervisor support for experimental design

**视觉建议：** 一张已经跑出来的 CSV 曲线截图（证明数据管线可用）

**讲稿：**
> Is this feasible? The car is already built and wired, following a tested wiring checklist. The firmware already produces exactly the kind of data I need — this plot on the right came out of a real test run last week. The only engineering work left is one S-curve generator function, which is a matter of weeks, not months. All components are cheap and common, so anything that breaks can be replaced quickly, and my supervisor reviews the experimental design with me.

## Slide 10 — Feasibility: Skills, Risks & Backups（0:40）

**幻灯片内容：**
- Skills in hand: Arduino/ESP32 programming · Python data logging (pyserial, pandas) · PID theory from Åström & Hägglund
- Risk → Mitigation:
  - INA226 sensor drops out → auto-reconnect in firmware + multimeter cross-check
  - Battery voltage drifts → fixed voltage window per session + voltage logging
  - Quantisation noise at short sampling → 100 ms period, low-pass filter, 3+ repeats
  - Schedule slip → 6-week buffer before submission
- Ethics & safety: low voltage (≤9 V), bench-tested, wheels off ground first

**讲稿：**
> On skills: I already write the firmware, the Python logger and the analysis myself, and the PID theory is covered by the literature. Key risks and my mitigations: if the power sensor drops out, the firmware reconnects automatically and I can cross-check with a multimeter. If the battery voltage drifts, I test within a fixed voltage window and log voltage with every sample. Encoder noise is handled by the 100-millisecond sampling period, a low-pass filter and repeated trials. And the timeline carries a six-week buffer. Safety is simple: everything runs below nine volts, and new behaviours are always bench-tested with the wheels off the ground first.

## Slide 11 — Timeline（0:45）

**幻灯片内容（表格或甘特图）：**

| Phase | Time | Deliverable |
|---|---|---|
| S-curve generator + pilot tests | Aug–mid Sep 2026 | tested open-loop mode |
| Main experiments A–E + repeats | mid Sep–Nov 2026 | complete CSV dataset |
| Extension (combined strategy) | Nov–Dec 2026 | extra dataset |
| Data analysis + literature write-up | Dec 2026–Jan 2027 | figures, draft review section |
| Report writing | Jan–Feb 2027 | first full draft |
| Revision + supervisor review | Mar 2027 | second draft |
| Buffer + proofreading + submission | Apr 2027 | final report (06/27 series) |

**讲稿：**
> Here is my plan from now to submission. By mid-September I will finish the S-curve generator and pilot tests. The main experiments with repeats run through November, and December gives room for the combined-strategy extension. January is for analysis and the literature write-up, February and March for drafting and revising the report with my supervisor's feedback, and April is buffer, proofreading and submission. Every phase ends with a concrete deliverable, so slippage is visible early.

## Slide 12 — Summary & Expected Contribution（0:30）

**幻灯片内容：**
- Same car, same task, two strategies — measured, not assumed
- Outcomes: energy vs. time trade-off **+** quantified differential suppression
- Deliverable: evidence-based guidance for battery-powered robots; open dataset
- Thank you — Questions?

**讲稿：**
> To summarise: on one car, under identical conditions, I will measure — not assume — the energy and time trade-off between S-curve planning and PID feedback, and quantify the one thing only feedback can do: keeping two mismatched motors running at the same speed. The result is evidence-based guidance for anyone building battery-powered robots. Thank you — I am happy to take questions.

---

## 讲述小贴士

- 数字要说得出处：5% 差速、10 Hz、100 ms、330 counts/rev、±5% 稳定带——都来自你的真实系统，被追问时用 Slide 6/8 的数据回答。
- 全场只讲一个故事：“我造了车 → 车有两个毛病（耗电、跑偏）→ 两种经典方案各管一半 → 我用同一辆车量化谁换来什么”。
- 时间控制：Slide 7 最容易超时，超了就砍 C（调参）的展开描述，只念加粗部分。

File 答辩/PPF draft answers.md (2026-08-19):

# IPQ Project Proposal Form — 答案草稿

> 与 `project proposal form - IPQ draft.docx` 内容一致，方便复制修改。
> 修改后如需同步回 Word，直接替换对应表格里的文字即可。
> 待你自己填写：Candidate number（大考 4 位考号）、Candidate name（护照拼音名）。

## Research question

How do S-curve open-loop motion profiling and PID closed-loop control compare in terms of the electrical energy consumed and the time taken to complete a speed-change task on a self-built two-motor robot car, and to what extent can PID control additionally suppress the wheel-speed difference between the two motors — a problem that open-loop control cannot solve?

## Briefly explain why you have chosen this question and topic

My interest in this topic began when I was building and testing my own two-motor robot car. I noticed that the motors were by far the biggest power consumers on the car: they drained the battery quickly, and a large part of the electrical energy appeared to be wasted rather than converted into useful motion. This made me ask whether the way the motors are commanded could change how much energy a movement costs. A second observation followed: when both motors received the same PWM command, the two nominally identical wheels ran at measurably different speeds (about 5% apart, shown by the wheel encoders), so the car drifted off a straight line.

In the literature there are two mainstream answers to "how should a robot command its motors". One is S-curve motion profiling: the speed reference follows a smooth, jerk-limited S-shaped curve, the standard approach in CNC machines and industrial robots because it limits vibration and mechanical stress (Nguyen et al., 2008; Meckl et al., 1998). The other is PID feedback control, the most widely used control algorithm in industry, which continuously corrects the motor input based on the measured speed error (Åström & Hägglund; Mahmud et al., 2020; Hammoodi et al., 2020).

However, most published comparisons are simulation-based and assume a single, idealised motor. On real low-cost hardware the two "identical" motors are not identical, and everything runs on a battery, so two practical questions remain open: which strategy completes a movement using less energy and less time, and which one can handle the motor mismatch that makes my car veer off course? An S-curve profile is open-loop: however well it is planned, it cannot see or correct the speed difference between the two wheels. PID feedback, in principle, can — and quantifying this difference in capability is exactly what I want to do.

The answer has practical value for battery-powered mobile robots and for student robotics projects: if one strategy saves energy and time while the other uniquely guarantees straight-line tracking, choosing between them (or combining them) becomes an evidence-based engineering decision. The project also develops my skills in control engineering, embedded programming and experimental data analysis, which I plan to study further at university.

## Outline the research method(s) you will use and explain how this will help you to answer your research question

**Basic assumptions.** (1) The speed difference between the two motors under identical PWM commands (about 5%) is stable and repeatable, so it can be treated as a systematic error that feedback can cancel. (2) An S-curve speed profile can be generated on board the ESP32 and applied to both motors as a time-varying open-loop PWM reference, while PID uses the encoder-measured wheel speeds as feedback — so both strategies can be tested on the same car under identical conditions. (3) Energy per task, taken as the time integral of electrical power measured by the INA226 sensor, and task time, taken as the time from the command until the wheel speed settles within a fixed band of the target, are fair and valid indicators for comparing the two strategies.

**Research method.** A quantitative controlled-experiment design. Independent variable: control strategy (S-curve open-loop profile vs. tuned PID feedback). Dependent variables: electrical energy per movement (J), task/settling time (s), steady-state speed error, wheel-speed difference (rpmL − rpmR) and yaw rate (gyrZ, an independent measure of the car turning). Controlled variables: the same car, surface, battery voltage range, target speeds and test routine. Each condition is repeated at least three times and analysed with means, standard deviations and plots (Excel / Python). A dedicated experiment then tests the unique capability: identical S-curve commands sent to both wheels vs. independent PID control of each wheel, measuring how much feedback reduces the speed difference and the straight-line drift.

**Technical route.** (1) Literature review of PID tuning theory and S-curve planning algorithms, from which the evaluation metrics and a fair test protocol are derived. (2) Platform: my existing robot car — ESP32 controller, two JGB37-520B encoder motors, DRV8833 driver, INA226 voltage/current sensor and MPU6050/LSM6 gyroscope — whose firmware already implements dual-wheel PID with anti-windup and logs all telemetry (target, wheel speeds, PWM, yaw rate, voltage, current, power) at 10 Hz to CSV; I will add an S-curve reference generator for the open-loop mode. (3) Experiments: A — the same speed-change task under S-curve vs. PID, comparing energy and time; B — step-response measurement; C — one-factor-at-a-time PID gain tuning (Kp, Ki, Kd, feed-forward); D — the differential-suppression test; E — robustness checks at several target speeds. (4) Data analysis and conclusions; if time allows, testing a PID loop that tracks an S-curve reference as a combined strategy.

**How this helps answer the research question.** Experiments A and E provide the direct energy and time comparison; B and C ensure the PID side is fairly tuned rather than misrepresented; D quantifies the wheel-speed suppression that only feedback can provide. Repeated trials and statistical analysis show how reliable each conclusion is.

**Resources required.** The robot-car platform and instruments above (already built and working); a laptop with the Arduino IDE (ESP32 toolchain) and Python (pyserial for data logging, pandas/matplotlib for analysis); batteries and a multimeter; the literature and datasheets listed below; and my supervisor's advice on experimental design.

## Outline the main sources of information you have identified for the project

**Academic literature:**

1. Åström, K. J. & Hägglund, T. — *PID Controllers: Theory, Design and Tuning* (ISA). Foundational PID theory and tuning rules.
2. Mahmud, M., Motakabber, S. M. A., Alam, A. H. M. Z. & Nordin, A. N. (2020). "Control BLDC Motor Speed using PID Controller", *International Journal of Advanced Computer Science and Applications* 11(3). PID speed-controller design.
3. Hammoodi, S. J., Flayyih, K. S. & Hamad, A. R. (2020). "Design and implementation speed control system of DC Motor based on PID control and Matlab Simulink", *International Journal of Power Electronics and Drive Systems* 11(1). PID implementation for DC motors.
4. Bansal, U. K. & Narvey, R. (2013). "Speed Control of DC Motor Using Fuzzy PID Controller", *Advances in Electronic and Electric Engineering* 3(9). Advanced PID variants, for context on the limits of classical PID.
5. Nguyen, K. D., Ng, T.-C. & Chen, I.-M. (2008). "On Algorithms for Planning S-curve Motion Profiles", *International Journal of Advanced Robotic Systems* 5(1). General algorithms for S-curve trajectory planning.
6. Meckl, P. H., Arestides, P. B. & Woods, M. C. (1998). "Optimized S-Curve Motion Profiles for Minimum Residual Vibration". Optimising S-curve profiles to reduce vibration — the classic argument for S-curve motion.

**Databases and search tools:** Google Scholar, IEEE Xplore, ScienceDirect and ResearchGate, searched with keywords such as "S-curve motion profile", "PID DC motor speed control" and "differential drive control".

**Technical documentation and open-source resources:** the Espressif ESP32 Arduino core documentation (GitHub), the Texas Instruments INA226 and DRV8833 datasheets (power measurement and motor driving), the InvenSense MPU6050 / ST LSM6 sensor documents, and open-source PID code such as Brett Beauregard's Arduino PID library as implementation references.

**Primary data:** telemetry CSV logs recorded from the car itself (target speed, both wheel speeds, PWM, yaw rate, voltage, current and power at 10 Hz) — the main evidence base of the project.

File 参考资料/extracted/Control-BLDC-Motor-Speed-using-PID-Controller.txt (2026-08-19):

(IJACSA) International Journal of Advanced Computer Science and Applications, 
Vol. 11, No. 3, 2020 
477 | P a g e  
www.ijacsa.thesai.org 
Control BLDC Motor Speed using PID Controller 
Md Mahmud1, S. M. A. Motakabber2, A. H. M. Zahirul Alam3, Anis Nurashikin Nordin4 
Department of Electrical and Computer Engineering 
International Islamic University Malaysia 
Kuala Lumpur, Malaysia 

Abstract—At present, green technology is a major concern in 
every country around the world and electricity is a clean energy 
which encourages the acquisition of this technology. The main 
applications of electricity are made through the use of electric 
motors. Electric power is converted to mechanical energy using a 
motor, that is to say, the major applications of electrical energy 
are accomplished through electric motors. Brushless direct 
current (BLDC) motors have become very attractive in many 
applications due to its low maintenance costs and compact 
structure. The BLDC motors can be substituted to make the 
industries more dynamic. To get better performance BLDC 
motor requires control drive facilitating to control its speed and 
torque. This paper describes the design of the BLDC motor 
control system using in using MATLAB/SIMULINK software for 
Proportional Integral Derivative (PID) algorithm that can more 
effectively improve the speed control of these types of motors. 
The purpose of the paper is to provide an overview about the 
functionality and design of the PID controller. Finally, the study 
undergoes some well-functioning tests that will support that the 
PID regulator is far more applicable, better operational, and 
effective in achieving satisfactory control performance compared 
to other controllers. 
Keywords—PID controller; green technology; fuzzy logic 
control; speed control; BLDC motor 
I. 
INTRODUCTION 
The present era is the era of the industrial revolution, which 
began with the invention of motor. Various types of motors 
have been developed over time, but these motors are generally 
classified into two main categories, namely, AC motor and DC 
motor. There exists a set of DC motors that can be used on 
different devices. However, generally two types of DC motors 
are set up in industrial applications. In the first type, the 
magnetic flux is generated by the current through the field coil 
of static pole structure and in the second type, permanent 
magnet supplies the required air gap flux [1]. A BLDC motor 
is a special type of DC motor that does not apply a brush for 
transport, instead an electronic process system is used for this 
purpose. The BLDC motor is usually a synchronous motor 
composed of a trapezoidal back EMF waveform and a 
permanent magnet. The current trend shows that high-
performance BLDC motor technologies are widely used for 
global industrial applications and variable speed drives in 
electric vehicles [2]. In fact, these types of motors depend on 
its control circuit. In fact, these types of motors rely on its 
control circuit and still developing a high performance circuit 
is a challenging task for researchers. A basic control system is 
shown in Fig. 1 for the BLDC motor. 
The structure of the BLDC motor tuning control project 
selection, modelling simulation and so on. The design structure 
of a BLDC motor is a complex task and depends on many 
issues such as project selection, modeling, simulation, etc. In 
terms of the rapidity framework of the BLDC motor, a host of 
modern control solutions have been proposed [3]. 
The key features of a conventional PID controller algorithm 
are it is easily adjustable, steady operation and its simple 
design, which making it widely used for controlling system. 
For practical reason, common speed control structure is applied 
in the PID controller. The mathematical model and speed 
control of the BLDC motor have been proposed and validated 
using fuzzy logic and PID controller [4]. Most of the cases a 
different finding is seen in terms of practical utility experiences 
where the volatility of well-structured prototype, different units 
of nonlinear, low variability have been at work. For tuning a 
PID controller parameters are not that simple, hence, getting 
the optimal position under the examined circumstances is 
challenging [5]. This study proposes a PID controller through 
modifying some changes thereto which, may increase the 
regulation speed of BLDC motor. In this case parameters can 
be tuned at the actual moment under PID controller operation. 
In the sake of better functioning of the PID controller scheme 
requires input and membership function enhancement [6]. At 
the same time, a set of values are applied for the PID 
controller’s constant coefficients, Kp, Ki and Kd. By employing 
these values, the proposed modified controller would be 
restructured to any adjusting dimension. 
The purpose of this study is to show the dynamic response 
to the rapid tuning results of the proposed modified PID 
controller; which can help to control the speed of the motor and 
to maintain constant speed during load changes. Thus, the PID 
regulator can increase the overall performance of the BLDC 
motor. The simulation results showed that the functions of the 
PID controller could be provided with a better control 
performance [7]. 
 
Fig 1. 
Basic Circuit Diagram for the BLDC Motor Control System. 
(IJACSA) International Journal of Advanced Computer Science and Applications, 
Vol. 11, No. 3, 2020 
478 | P a g e  
www.ijacsa.thesai.org 
II. BLDC MOTOR AND SPEED CONTROL SYSTEM 
A. Speed Control System 
A controller circuit is essential to operate and control the 
speed of a BLDC motor. There are many types of speed control 
system developed for controllers but the speed controllers have 
to modernize with the ages. However, they are generally 
classified as closed loop and open loop control systems, 
respectively. Closed loop techniques are used for high accuracy 
control system. Fig. 2 shows a BLDC motor speed controller 
block diagram using two closed loop systems. In this case, the 
internal loop is used for tuning and sense the power supply 
polarity and the external loop is used to control the speed. The 
motor speed controller helps to adjust the voltage of the DC 
bus. To control the system, DC supply is required and its value 
depends on the motor speed (rpm) and its capacity. This system 
also requires a controller, in which case a PID controller is 
used that ultimately controls the inverter output voltage. A 
sensor is an integral part of a closed loop controller for 
controlling the speed of a motor. The primary function of the 
sensor is to convert the physical position and condition of the 
motor shaft into an equivalent electrical signal for the 
controller circuit. Typically, BLDC motor requires an AC-like 
voltage-waveform for its operation, so inverter circuit is used 
to convert the DC power supply voltage into an equivalent AC 
supply voltage [8], [9] for proper function. 
B. The Back Electro Motive Fource (BEMF) 
Typically, a 3-phase BLDC motor uses six electronic 
switches (power transistors) to produce 3-phase voltage 
simultaneously to a full-bridge configuration power converter. 
The transistors have a rotor position, which will be defined as 
the switching sequence. Most of the cases motor starter is 
monitoring by using three hall sensor devices. The hall sensors 
provide the information to the decoder block for producing the 
sign of reference current signal vector to the back 
electromotive force (BEMF). To operate the motor in the 
opposite direction, the current is changed in reverse direction 
or the switching order of the controller is changed. 
The MATLAB simulation block diagram for generating the 
back EMF of the decoder is shown in Fig. 3, and Table I shows 
the decoder sequences of the proposed 3-phase PID controller 
for the BLDC motor to rotate in the clockwise direction. 
 
Fig 2. 
Block Diagram of BLDC Motor Speed Control. 
 
Fig 3. 
Back EMF of Decoder for MATLAB Drive. 
TABLE I.  
TRUE TABLE FOR DECODER 
Table I. 
True Table For Decoder  
ha 
hb 
hc 
emf_a 
emf_b 
emf_c 
 
0 
0 
0 
0 
0 
0 
0 
0 
1 
0 
-1 
+1 
0 
1 
0 
-1 
+1 
0 
0 
1 
1 
-1 
0 
+1 
1 
0 
0 
+1 
0 
-1 
1 
0 
1 
+1 
-1 
0 
1 
1 
0 
0 
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
Similarly, Fig. 4 shows the functional block diagram of the 
inverter switching for MATLAB simulation, and Table II 
shows the decoder sequences of the proposed 3-phase PID 
controller 
for 
the 
BLDC 
motor 
to 
rotate 
in 
the 
counterclockwise motion. 
 
Fig 4. 
Inverter Switching for MATLAB Drive. 
(IJACSA) International Journal of Advanced Computer Science and Applications, 
Vol. 11, No. 3, 2020 
479 | P a g e  
www.ijacsa.thesai.org 
TABLE II.  
TRUE TABLE FOR INVERTER SWITCHING 
Table 
II. 
 
True Table For Inverter Switching 
emf_a 
emf_b 
emf_c 
Q1 
Q2 
Q3 
Q4 
Q5 
Q6 
 
0 
0 
0 
0 
0 
0 
0 
0 
0 
0 
-1 
+1 
0 
0 
0 
1 
1 
0 
-1 
+1 
0 
0 
1 
1 
0 
0 
0 
-1 
0 
+1 
0 
1 
0 
0 
1 
0 
+1 
0 
-1 
1 
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
III. PROPOSED PID CONTROLLER MODELING 
For getting better performance of DC motors it is essential 
to use a controller circuit. For this purpose, a variety of 
controller circuits and algorithms are used. However, among 
them PID controller is the most suitable controller circuit for 
BLDC motor. The PID controller is mainly composed of three 
block of circuits and they are proportional, integral and 
derivative blocks. Each block of circuit is used to perform 
different mathematical operations as their name mentioned. 
The complete MATLAB design of the proposed controller for 
3-phase brushless DC motor is shown in Fig. 5. The diagram 
clearly shows how the reference source, PID controller, driver 
circuit, sensors, converter circuit, inverter circuit, display scope 
and motor are interconnected. 
The foundational frequency transferring performance G(s) 
of the PID controller can be represented by (1) and (2), 
G(s) = Kp + Ki /s +Kd s 

         (1) 
G(s) = (Kd s2 + Kp s + Ki)/s        
              
         (2) 
Where, Kp = proportional gain coefficient, Ki = integral 
gain coefficient, Kd = derivative gain coefficient and s is the 
complex frequency.  
The time derivative output U(t) of the controller for control 
of the plant is equal to Kp times the magnitude of error pulse Kd 
times the derivative of time function error signal e(t) and Ki 
times the integral can be represented by (3). 
U(t) = Kp e(t) + Ki ∫e(t)dt + Kd de(t)/dt 
 
        (3) 
 
Fig 5. 
Complete MATLAB Design of Controller for BLDC Motor. 
Its applications are wide because of its ease and outstanding 
performance, in many cases its efficiency is more than 95%. 
Typically a closed-loop PID controller is used for industry 
application. The four key features are most interested in the 
response to the closed-loop step, they are, settling time, 
overshoot, steady-state error and response time. 
Table III shows the values of the PID controller parameters 
used for this design. 
TABLE III.  
VALUES OF THE PID CONTROLLER PARAMETERS 
Table III 
Values Of The PID Controller Parameters 
Method 
Kp 
Ki 
Kd 
 
PID 
100 
0.5 
500 
IV. RESULT AND DISCUSSION 
The performance of the proposed PID controller for 
brushless DC motor at 2500 rpm is shown in Fig. 6. In this 
figure, X and Y axis represented the time in second (sec) and 
the speed (rpm) of the BLDC motor at no-load condition 
respectively. From the figure, it is seen that the settling time of 
the controller is about 0.018 sec with a negligible amount of 
overshoot and undershoot. After 0.018 sec the motor runs at a 
constant speed of the preset value 2500 rpm. 
Fig. 7 shows the output torque response performance of the 
BLDC motor at no-load condition. In this figure, X and Y axis 
represented the time in second (sec) and electromagnetic 
torque value in Newton-meter (Nm) of the BLDC motor at no-
load condition, respectively. From the figure, it is observed that 
the motor electromagnetic torque (Nm) is fixed after about 
0.030 sec. 
 
Fig 6. 
The no-load performance of the BDC motor using. 
 
Fig 7. 
Time Versus Electromagnetic Torque Response of the BLDC Motor. 
(IJACSA) International Journal of Advanced Computer Science and Applications, 
Vol. 11, No. 3, 2020 
480 | P a g e  
www.ijacsa.thesai.org 
Fig. 8 shows the stator current of the BLDC motor at no-
load condition. In this figure X-axis represented the time in 
second (secs) and Y-axis the motor stator current in Ampere 
(A) respectively. In this figure the 3-phase stator currents are 
illustrated by the green, pink and yellow color lines 
respectively. It is also observed that the stators current are 
fixed after 0.030 (secs) which is the same as electromagnetic 
torque fixing time of the result as shown in Fig. 6. 
Fig. 9 shows the back electromotive force (emf) of the 
BLDC motor at no-load condition. In this figure, X and Y axis 
represented the time in second (secs) and back emf value in 
Volt (V) of the BLDC motor at no-load condition respectively. 
The 3-phase back emf voltages of the BLDC motor are 
illustrated by the green, pink and yellow color lines in this 
figure, respectively. It is clear from the figure that the 3-phase 
back emf voltages are fixed ±24V after 0.030 (secs), which 
justifies the result same as the results obtained in Fig. 6 and 
Fig. 8. 
Fig. 10 shows the 3-phase signals generated from Hall-
sensor. Here the green, pink and yellow color lines are 
represented the individual phase signal generated by the sensor. 
 
Fig 8. 
Phase Stator Current of the BLDC Motor. 
 
Fig 9. 
BLDC Motor 3-Phase Back Electromotive Force. 
 
Fig 10. BLDC Motor Hall Effect Signal. 
Fig. 11 shows the output performance of the PID controller. 
The X-axis and Y-axis represented the second (secs) and 
reference signal value in RPM of the PID controller, 
respectively. From the diagram, it is seen that the PID 
controller output under shoot and reach minimum value about 
0.03 sec, then it reach at a stable condition after about 0.03 sec. 
Fig. 12 shows the performance comparison of the PI, PID 
and Fuzzy logic controller. In this figure X-axis and Y-axis 
represented the time in second (secs) and electromagnetic 
torque value in Newton-meter (Nm) of the BLDC motor at no-
load condition, respectively. Here, the red, yellow and green 
color lines are illustrated the PI, PID and Fuzzy logic 
controllers output performance in some respects. It is 
noteworthy that the performance of the PID controller is better 
than the other two controllers. The BLDC motor predetermined 
reference speed of 2500 rpm has been chosen in this study. 
From Fig. 6 and Fig. 12 it is observed that the PID 
controller settlement time about 18 milliseconds (msecs). The 
overshoots and undershoots of this controller are 0.4% and 
1.9%, respectively, which is within the tolerable range of a 
BLDC motor for suitable operation. The PID controller slew 
rate about 92.27 (msecs) and per shoot 2.5%. 
On the other hand, PI controller rise time is better than the 
PID controller but, its slow rate is much higher as 621.35 
(msecs). In the other aspects of the PI controller, the pre-shoot 
0.66%, overshoot 32.67%, undershoot 1.68% and settling time 
15.20 msec. The pre-shoot, overshoot and undershoot are 
basically a high frequency nose and can be minimized by using 
filter [10]. 
 
Fig 11. PID Controller Output Performance with Time. 
 
Fig 12. Performance Comparison among PI, PID and Fuzzy Logic 
Controllers. 
(IJACSA) International Journal of Advanced Computer Science and Applications, 
Vol. 11, No. 3, 2020 
481 | P a g e  
www.ijacsa.thesai.org 
It shows that the output of the Fuzzy logic controller, the 
pre-shoot 0.67%, slew rate 598.15 (msecs), overshoot 30.92%, 
undershoot 3.2% and settling time 9.2 (msecs). 
From 
comparative 
performance 
analysis 
it 
is 
understandable that the PID controller will provide the best 
results for BLDC motor control. 
V. CONCLUSION 
A 
three-phase 
BLDC 
motor 
controller 
has 
been 
successfully designed based on PID controller scheme and 
compared its performance with PI and Fuzzy logic controllers. 
From the results, it is observed that the PID controller provides 
the best performance compared to the other two controllers, PI 
and Fuzzy logic. The design has been validated by MATLAB 
simulation. 
ACKNOWLEDGMENT 
This research has been supported by the Malaysian 
Ministry of Education through the Fundamental Research 
Grant Scheme under the project ID: FRGS19-054-0662. 
REFERENCES 
[1] H. Salim Hameed, “Brushless DC Motor Controller Design Using 
Matlab Applications,” 3rd Scientific Conference of Engineering Science 
(ISCES), 19 April 2018. 
[2] M. Rajkumar, G. Ranjhitha, G. Pradeep and M. F. Kumar, “Fuzzy-based 
Speed Control of Brushless DC Motor feed electric vehicle,” IJISSET, 
2017, vol. 3(3). 
[3] K. Swapnil, J. Anjali, A. Mohan and D. Shantanu, “Modeling and 
control of a permanent-magnet brushless DC motor drive using a 
fractional-order proportional-integral-derivative controller,” Turkish 
Journal of Electrical Engineering and Computer Sciences, 2017, 25(5), 
pp. 4223-4241. 
[4] M. Valan Rajkumar, G. Ranjhitha, M. Pradeep, M. Fasil PK and R. 
Sathish Kumar, “Fuzzy based Speed Control of Brushless DC Motor fed 
Electric Vehicle,” International Journal of Innovative Studies in 
Sciences and Engineering Technology (IJISSET), 2017, vol. 3(3). 
[5] H. Manal and Jasim, “Tuning of a PID Controller by Bacterial Foraging 
Algorithm for Position Control of DC Servo Motor,” Iraqi Academic 
Scientific Journals, 2018, vol. 36. 
[6] M. Singirala, D. Krishna and T. Anil Kumar, “Improving Performance 
Parameters of PMBLDC Motor using Fuzzy Sliding Mode Controller,” 
International Journal of Recent Technology and Engineering (IJRTE), 
2019, vol. 8(4). 
[7] M. Rafay Khan, A. Ahmed Khan and U. Ghazali, “Speed Control of DC 
Motor under Varying Load Using PID Controller,” International Journal 
of Engineering (IJE), 2015, vol. 9(3). 
[8] T. Rahman, S. M. A. Motakabber, M. I. Ibrahimy and A. H. M. Zahirul 
Alam,  “PLL-Based 3φ Inverter Circuit for Microgrid System Operated 
by Electrostatic Generator,” IIUM Engineering Journal, 2019, vol. 
20(1), pp. 177-193. 
[9] T. Rahman, S. M. A. Motakabber, M. I. Ibrahimy and Aliza ‘Aini, “A 
PWM Controller of a Full Bridge Single-phase Synchronous Inverter for 
Micro-grid System,” Journal of Physics: Conference Series, 2017, pp.1-
13. 
[10] S. M. A. Motakabber, M. A. Mohd Ali and N. Amin, “Computer Aided 
Design of an Active Notch Filter for HF Band RFID,” FREQUENZ, 
2010, vol. 64(1-2), pp. 23-25.

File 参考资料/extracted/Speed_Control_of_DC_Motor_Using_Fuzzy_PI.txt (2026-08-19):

Advance in Electronic and Electric Engineering. 
ISSN 2231-1297, Volume 3, Number 9 (2013), pp. 1209-1220 
© Research India Publications 
http://www.ripublication.com/aeee.htm 

Speed Control of DC Motor Using Fuzzy PID Controller 

1Umesh Kumar Bansal and 2Rakesh Narvey 
 
1Dept. of Electrical Engineering, M.I.T.S. Gwalior. 
2Assistant Professor, Dept. of Electrical Engineering, M.I.T.S. Gwalior. 

Abstract 
 
In this paper we have designed a DC motor whose speed can be 
controlled using PID controller. The proportional, integral and derivate 
(KP, KI, KD) gains of the PID controller are adjusted according to 
FUZZY LOGIC. First, the fuzzy logic controller is designed according 
to fuzzy rules so that the systems are fundamentally robust. There are 
25 fuzzy rules for self-tuning of each parameter of PID controller. The 
FLC has two inputs. One is the motor speed error between the 
reference and actual speed and the second is change in speed error 
(speed error derivative).Secondly, the output of the FLC i.e. the 
parameters of PID controller are used to control the speed of the DC 
Motor. The study shows that both precise characters of PID controllers 
and flexible characters of fuzzy controller are present in fuzzy self-
tuning PID controller. The fuzzy self-tuning approach implemented on 
a conventional PID structure was able to improve the dynamic as well 
as the static response of the system. Comparison between the 
conventional output and the fuzzy self-tuning output was done on the 
basis of the simulation result obtained by MATLAB. The simulation 
results demonstrate that the designed self-tuned PID controller realize 
a good dynamic behavior of the DC motor, a perfect speed tracking 
with less rise and settling time, minimum overshoot, minimum steady 
state error and give better performance compared to conventional PID 
controller. 
 
Keywords: Fuzzy logic, PID controller, DC motor drives speed 
control. 

Umesh Kumar Bansal & Rakesh Narvey 
 
1210
1. Introduction 
The development of high performance motor drives is very important in industrial as 
well as other purpose applications such as steel rolling mills, electric trains and 
robotics. Generally, a high performance motor drive system must have good dynamic 
speed command tracking and load regulating response to perform task. DC drives, 
because of their simplicity, ease of application, high reliabilities, flexibilities and 
favorable cost have long been a backbone of industrial applications, robot 
manipulators and home appliances where speed and position control of motor are 
required.  
DC drives are less complex with a single power conversion from AC to DC. Again 
the speed torque characteristics of DC motors are much more superior to That of AC 
motors. A DC motors provide excellent control of speed for acceleration and 
deceleration. DC drives are normally less expensive for most horsepower ratings. DC 
motors have a long tradition of use as adjustable speed machines and a wide range of 
options have evolved for this purpose. In these applications, the motor should be 
precisely controlled to give the desired performance. The controllers of the speed that 
are conceived for goal to control the speed of DC motor to execute one variety of 
tasks, is of several conventional and numeric controller types, the controllers can be: 
proportional integral (PI), proportional integral derivative (PID) Fuzzy Logic 
Controller (FLC) or the combination between them: Fuzzy-Neural Networks, Fuzzy-
Genetic Algorithm, Fuzzy-Ants Colony, Fuzzy-Swarm[10]. The proportional – 
integral – derivative (PID) controller operates the majority of the control system in the 
world. It has been reported that more than 95% of the controllers in the industrial 
process control applications are of PID type as no other controller match the simplicity, 
clear functionality, applicability and ease of use offered by the PID controller [3], [4]. 
PID controllers provide robust and reliable performance for most systems if the PID 
parameters are tuned properly. 
The major problems in applying a conventional control algorithm (PI, PD, PID) in 
a speed controller are the effects of non-linearity in a DC motor. The nonlinear 
characteristics of a DC motor such as saturation and fiction could degrade the 
performance of conventional controllers [1], [2].Generally, an accurate nonlinear 
model of an actual DC motor is difficult to find and parameter obtained from systems 
identification may be only approximated values. The field of Fuzzy control has been 
making rapid progress in recent years. Fuzzy logic control (FLC) is one of the most 
successful applications of fuzzy set theory, introduced by L.A Zadeh in 1973 and 
applied (Mamdani 1974) in an attempt to control system that are structurally difficult 
to model. Since then, FLC has been an extremely active and fruitful research area with 
many industrial applications reported [5].In the last three decades, FLC has evolved as 
an alternative or complementary to the conventional control strategies in various 
engineering areas. Fuzzy control theory usually provides non-linear controllers that are 
capable of performing different complex non-linear control action, even for uncertain 
nonlinear Systems. Unlike conventional control, designing a FLC does not require 
precise knowledge of the system model such as the poles and zeroes of the system 
Speed Control of DC Motor Using Fuzzy PID Controller 
1211 
 
transfer functions. Imitating the way of human learning, the tracking error and the rate 
change of the error are two crucial inputs for the design of such a fuzzy control system 
[6], [7]. 

2. Speed Control of DC  
2.1 Motor  

Fig 1: Model of DC Motor. 
 
DC motors are most suitable for wide range speed control and are there for many 
adjustable speed drives. Intentional speed variation carried out manually or 
automatically to control the speed of DC motors. 
α (Va-IaRa)/Ԅ  
 
= (Va -IaRa)/KaԄ  
Where Ԅ = Field flux per pole 
 
Ka= Armature constant = PZ/2πa 
 
Where P = No. of poles, Z = Total no. of armature conductor, a = No. of parallel 
path 
 
From the equation (1) it is clear that for DC motor there are basically 3 method of 
speed control. 
They are:- 
1- Variation of resistance in armature circuit. 
2- Variation of field flux. 
3- Variation of armature terminal voltage 

3. Modeling of DC Motor 
From fig.1The armature voltage equation is given by: Va =Eb+ IaRa+ La (dIa/dt) 
Umesh Kumar Bansal & Rakesh Narvey 
 
1212
Now the torque balance equation will be given by Tm = Jmdω/dt +Bmω+TL ----I 
Taking field flux as Φ and Back EMF Constant as K. 
Equation for back emf of motor will be 
Eb = Kɸɷ------II 
Tm= KɸIa----III 
Taking laplace transform of the motor‟s armature voltage equation 
Ia(S) = (Va – Eb)/ (Ra + LaS) 
Now, taking equation (ii) into consideration, we have: Ia(s) = (Va – KΦω)/ Ra (1+ 
LaS/Ra) 
 
And ω(s) = (Tm - TL) /JS = (KΦIa - TL) /JmS (Armature Time Constant) 
Ta=La/Ra 

Fig. 2: Modelling Block diagram of DC Motor. 
 
After simplifying the above motor model, the overall transfer function will be 
ω (s) / Va(s) = [KΦ /Ra] /JmS(1+TaS) /[ 1 +(K²Φ² /Ra)/JmS(1+TaS)] 
Tm= Jmdω/dt = KΦIa 
ω(s) = [(Ra / Km) Ia(s) - TL Ra / (Km) ² ] (1/Tem(s)) 
 
Now, Replacing KΦ by Km in equation (v), we will get: ω(s) /Va(s)=(1/Km) / 
(1+STem+S²TaTem) 
 
The armature time constant Ta is very much less than the electromechanical time 
constant Tem, (Ta <<Tem) 
Simplifying, 1 + STem + S²TaTem ≈ 1 + S (Ta+Tem) +S²TaTem = (1 + STem) (1 
+ STa) The equation can be written as: 
ω(s) /Va(s) = (1/Km)/((1 + STem)(1 + STa)) 
 
Tem and Ta are the time constants of the above system transfer function which will 
determine the response of the system. Hence the dc motor can be replaced by the 
transfer function obtained in above equation in the DC drive model. 
 
Speed Control of DC Motor Using Fuzzy PID Controller 
1213 
 
Table 1: Parameters of the DC Motor. 
 
Description of the parameter Parameter value 
Armature resistance (Ra) 
0.5Ω 
Armature inductance (La) 
0.02 H 
Armature voltage (Va) 
200 V 
Mechanical inertia (jm) 
0.1 Kg.m2 
Friction coefficient (Bm) 
0.008 N.m/rad/sec 
Back emf constant (k) 
1.25 V/rad/sec 
Rated speed 
1500 r.p.m 
Motor torque constant 
1 N.m/A 

4. Fuzzy Logic Controller 
Fuzzy systems are knowledge based or rule based systems. The heart of a fuzzy system 
is a knowledge base consisting of the so- called If-Then rules. A fuzzy If-Then 
statement in which some words are characterized by continuous membership functions. 
After defining the fuzzy sets and assigning their membership functions, rules must be 
written to describe the action to be taken for each combination of control variables. 
These rules will relate the input variables to the output variable using If-Then 
statements which allow decisions to be made. The If (condition) is an antecedent to the 
Then (conclusion) of each rule. Each rule in general can be represented in the 
following manner: 
If (antecedent) Then (consequence). 
For example: 
If the speed of the car is high, then apply less force to the accelerator. 
If pressure is high, then volume is small 
A fuzzy logic controller has four main components as shown in Figure: 
 
4.1 Fuzzification  
The success of this work, and the like, depends on how good this stage is conducted. In 
this stage, the crisp variables eω(k) and deω(k) are converted in to fuzzy variables e ω 
and de ω respectively. The membership functions associated to the control variables 
have been chosen with triangular shapes as shown in Fig. 2. The universe of discourse 
of all the input and output Variables are established as The suitable scaling factors are 
chosen to brought the input and output variables to this universe of discourse. Each 
universe of discourse is divided into seven overlapping fuzzy sets: NL (Negative 
Large), NM (Negative Medium), NS (Negative Small), ZE (Zero), PS (Positive Small), 
PM (positive Medium), and PL (Positive Large). Each fuzzy variable is a member of 
the subsets with a degree of membership μ varying between 0 (non-member) and 1 
(full-member). All the membership functions have asymmetrical shape with more 
crowding near the origin (steady state). This permits higher precision at Steady state 
[3]. 
121
4.2 
Kno
gov
func
that
kno
rule
AND
be u
pap
 
4
 
Inference e
owledge ba
verning the r
ctions. In th
t executes 2
owledge of t
e is expresse
D ( ce ω is 
used to prod
er, the Max
 
d
 
N
N
Z
P
P

engine  
ase involve
relationship
his stage, the
25 rules (5x5
the system 
ed in the fo
Positive La
duce the fu
x-product inf
T
de 
 
N
e  
NL 
 
PV
NS 
 
PM
ZE 
 
PV
PS 
 
PM
PL 
 
PV
s defining 
p between in
e variables e
5) as shown
behavior an
rm as in the
arge) THEN
zzy set valu
ference met
able1: Rule
NL 
NS
 
VL 
PV
ML 
PM
VS 
PV
ML 
PM
VL 
PV
Um
 
the rules 
nput and ou
e ω and ce ω
n in Table I
nd the expe
e following
N ( *qs ci is 
ues for the 
thod [3] is u
e base Param
S 
ZE
 
VL 
PVL
ML 
PML
VS 
PS
ML 
PML
VL 
PVL
mesh Kuma
represented
tput variabl
ω are proces
. These rule
erience of th
 example: I
Zero). Diffe
output fuzz
used 
meters for K
PS 
 
L 
PVL
L 
PL 
PMS
L 
PL 
L 
PVL
ar Bansal &
d as IF-TH
les in terms 
ssed by an in
es are estab
he control e
IF ( e ω is N
ferent inferen
zy variable 
Kp. 
PL 
 
PVL 
PVL 
PMS 
PVL 
PVL 
 Rakesh Na
 
HEN statem
of member
nference en
lished using
engineers. E
Negative La
nce engines
* qs ci . In
 
arvey 
ments 
rship 
ngine 
g the 
Each 
arge) 
s can 
n this 
Speed Control 

of DC Moto
T
de 

e
NL 
 
NS 
 
ZE 
 
PS 
 
PL 
 
Ta
De 
 
NL 
NS 
ZE 
PS 
PL 
or Using Fu
Table2: Rule
NL 
N
  
PM 
P
PMS 
P
PS 
P
PMS 
P
PM 
P
able 2: Rule
 
NL 
N
e  
 
PVS 
P
 
PMS 
P
 
PM 
P
 
PML 
P
 
PVL 
P
uzzy PID Co
 
e base Param
 
NS 
ZE
 
PM 
PM
PMS 
PMS
PS 
PVS
PMS 
PMS
PM 
PM
e base Param
 
NS 
ZE
 
PMS 
PM
PML 
PL
PL 
PL
PVL 
PVL
PVL 
PVL
 
ontroller
meters for K
PS 
 
PM 
S 
PMS 
S 
PS 
S 
PMS 
PM 
meters for K
PS 
P
 
M 
PL 
P
PVL P
PVL P
L PVL P
L PVL P
KI. 
PL 
 
PM 
PMS 
PS 
PMS 
PM 
 
KD. 
PL 
PVL 
PVL 
PVL 
PVL 
PVL 
 
1215 
121
fuzz
defi
con
the 
chan
or l
mai
imp
 
Con
Acc
to c
6
a) Rule ba
A decision
zy control a
initions. Th
ditions and 
rules and co
nge in error
less natural
intain for a
plemented u

b) Defuzz
The revers
ntroller (FL
cording to r
risp output.

ase  
n making lo
action from
he rules are 
the Then si
ompute a co
r (de). In a 
l language. 
a non- spe
sing conven
ification  
e of Fuzzif
LC) produce
real world r
 
ogic which 
m the knowl
in “If The
ide is called
ontrol signa
rule based c
A rule bas
ecialist end
ntional techn
fication is c
es required 
equirement
Um
 
is, simulati
ledge of the
en” format a
d the conclu
al depending
controller th
se controlle
d user and
niques. 
called Defu
output in 
s, the lingu
mesh Kuma
ing a huma
e control ru
and formall
usion. The c
g on the me
he control s
er is easy t
d an equiv
uzzification.
a linguistic
uistic variab
 
ar Bansal &
an decision
ules and lin
ly the If sid
computer is 
easured inpu
strategy is s
to understan
alent contr
 
. The use o
c variable (
les have to 
 Rakesh Na
n process, in
nguistic vari
de is called
able to exe
uts error (e)
stored in a m
nd and eas
roller could
of Fuzzy L
(fuzzy numb
be transfor
arvey 
nters 
iable 
d the 
ecute 
) and 
more 
sy to 
d be 
Logic 
ber). 
rmed 
Speed Control of DC Motor Using Fuzzy PID Controller 
1217 
 
In order to define fuzzy membership function, designers choose many different 
shapes based on their preference and experience. There are generally four types of 
membership functions used: 
1. Trapezoidal MF  
2. Triangular MF  
3. Gaussian MF  
4. Generalized bell MF  
 
Fig. 3: Structure of fuzzy logic controller. 
 
Implementation of an FLC requires the choice of four key factors 
1. Number of fuzzy sets that constitute linguistic variables.  
2. Mapping of the measurements onto the support sets.  
3. Control protocol that determines the controller behavior.  
4. Shape of membership functions.  
 
PID parameters fuzzy self-tuning is to find the fuzzy relationship between the three 
parameters of PID and "e" and "de", and according to the principle of fuzzy control, to 
modify the three parameters in order to meet different requirements for control 
parameters when "e" and "de" are different, and to make the control object a good 
dynamic and static performance [12]. 
 
4.3 Adjusting fuzzy membership functions and rules 
In order to improve the performance of FLC, the rules and membership functions are 
adjusted. The membership functions are adjusted by making the area of membership 
functions near ZE region narrower to produce finer control resolution. On the other 
hand, making the area far from ZE region wider gives faster control response. Also the 
performance can be improved by changing the severity of rules [15]. An experiment to 
study the effect of rise time (Tr), maximum overshoot (Mp) and steady-state error 
(SSE) when varying KP, KI and KD was conducted. The results of the experiment 
were used to develop 25-rules for the FLC of KP, KI and KD are the output variables 
and from error and change of error are the input variables. Triangular membership 
functions are selected. 

Umesh Kumar Bansal & Rakesh Narvey 
 
1218
 
Fig. 4: Block diagram of self-tuning fuzzy PID controller. 

Fig. 5: Simulink diagram self-tuning fuzzy PID Controller. 

Fig. 6: Error Vs time response of fuzzy tuned PID controlled DC motor 
 
0.5
Voltage Constant
speed
To Workspace
Spped Error
Speed
157.07
Reference speed
Rate of change of Speed error
e
u
Fuzzy_PID
du/dt
Derivative
Va
Speed
DC Motor
Spe
Fi
5. 
The
of D
fuzz
thre
tool
inte
and 
with
perf
bett
state
ed Control 
ig. 7: Chang
Fi

Conclusio
e steady stat
DC motor a
zy logic and
ee outputs 
lbox to des
egral and de
change in 
h the conv
formance in
ter dynamic
e error (SSE
 
of DC Moto
ge of speed 
ig. 6: Speed
on 
te operation
are studied.
d fuzzy set.
self-tuning 
sign fuzzy 
erivate (KP, 
speed error
ventional P
n both trans
c response c
E), high stea
or Using Fu
Vs Time re
d Vs time re
n and its var
 We have 
. This proje
fuzzy PID
controller. 
KI, KD) gai
r .From the 
PID contro
sient and st
curve, short
ady precisio
uzzy PID Co
 
sponse of fu
 
esponse of P
rious torque
also studied
ect introduce
D controller
The fuzzy 
ins of the P
simulation 
oller, self-tu
teady state 
ter response
on compared
ontroller
uzzy tuned P
PID controll
e-speeds, tor
d basic defi
es a design 
r and make
controller 
ID controlle
results it is
uning PID
response. T
e time, sma
d to the conv
 
PID control
 
led DC moto
rque-curren
finition and 
method of 
e use of M
adjusted th
er according
s concluded 
D controller
The self tu
all overshoo
ventional PI
1
lled DC mot
or. 
nt characteri
terminolog
f two inputs
MATLAB fu
he proportio
g to speed e
d that ,comp
r has a b
unning FLC
ot, small ste
ID controlle
1219 
tor 
istics 
gy of 
 and 
fuzzy 
onal, 
error 
pared 
better 
C has 
eady 
er. 
Umesh Kumar Bansal & Rakesh Narvey 
 
1220
References 
[1] 
B.J. Chalmers, “Influence of saturation in brushless permanent magnet 
drives.” IEE proc. B, Elect. Power Appl, vol.139, no.1, 1992 
[2] 
C.T. Johnson and R.D. Lorenz, “Experimental identification of friction and its 
compensation in precise, position controlled mechanism.” IEEE Trans. Ind, 
Applicant, vol.28, no.6, 1992. 
[3] 
Zhang, N. Wang and S. Wang, “A developed method of tuning PID 
controllers with fuzzy rules for integrating process,” Proceedings of the 
American Control Conference, Boston, 2004, pp. 1109-1114.  
[4] 
K.H. Ang, G. Chong and Y. Li, “PID control system analysis, design and 
technology,” IEEE transaction on Control System Technology, Vol.13, No.4, 
2005, pp. 559-576.  
[5] 
H.X.Li and S.K.Tso, "Quantitative design and analysis of Fuzzy Proportional-
Integral-Derivative Control- aStep towards Auto tuning", International journal 
of system science, Vol.31, No.5, 2000, pp.545-553. 
[6] 
Thana Pattaradej, GuanrongChen and pitikhate Sooraksa, "Design and. 
Implementation of Fuzzy PID Control of a bicycle robot" Integrated 
computer-aided engineering, Vol.9, No.4, 2002  
[7] 
Weiming Tang, Guanrong Chen and Rongde Lu, “A Modified Fuzzy PI 
Controller for a Flexible-joint Robot Arm with Uncertainties”, Fuzzy Set and 
System, 118 (2001) 109-119 
[8] 
PavolFedor, 
Daniela 
Perduková, 
“A 
Simple 
Fuzzy 
Controller 
Structure,”ctaElectrotechnica ETInformatica No. 4, Vol. 5, 2005. 
[9] 
Maher M.F. Algreer andYhyaR.M.Kuraz, “Design Fuzzy Self Tuning of PID 
Controller for Chopper-Fed DC Motor drive.” Kuraz. 
[10] Bomediene 
Alloua, 
Abdellah 
Laouf 
Brahim 
Gasbaoui 
and 
ABdessalamAbderrahamani, “Neuro-Fuzzy DC Motor speed Control Using 
Particle Swarm Optimization,” Leonaro Electronic Journal of Practices and 
Technologies ISSN,1583-1078.  
[11] ManafeddinNamazov and OnurBasturk, “DC motor position control using fuzzy 
proportional-derivative controllers with different defuzzification methods,” 
Turkish Journal of Fuzzy Systems (eISSN: 1309–1190), Vol.1, No.1, pp. 36-54, 
2010.  
[12] Wang Xiao-kan, Sun Zhong-liang, Wanglei, Feng Dong-qing, "Design and 
Research Based on Fuzzy PID-Parameters Self-Tuning Controller with 
MATLAB," Advanced Computer Theory and Engineering, International 
Conference on, pp. 996-999, 2008 International Conference on Advanced 
Computer Theory and Engineering, 2008 
[13] Gaddam Mallesham and Akula Rajani, “AUTOMATIC TUNING OF PID 
CONTROLLER USING FUZZY LOGIC.” 8th International Conference on 
DEVELOPMENT AND APPLICATION SYSTEMS Suceava, Romania, May 25 
– 27, 2006.  
[14] M.Chow and A. Menozzi ,”on the comparison of emerging and conventional 
techniques for DC motor control” proc.IECON ,PP.1008-1013,1992.

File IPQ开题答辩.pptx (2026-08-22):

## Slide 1

CAMBRIDGE INTERNATIONAL PROJECT QUALIFICATION · PROPOSAL DEFENSE

S-curve vs. PID
Energy, Time and Differential Suppression for a Two-Motor Robot Car

“Which control strategy moves my robot car faster and cheaper — and which one keeps it straight?”

[Your Name] · Centre CN213, Shanghai Guanghua College · Series 06/27
August 2026

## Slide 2

AGENDA

Outline

01
Background
& Motivation
why this question

02
Experimental
Design
variables · protocol · metrics

03
Feasibility
platform · skills · risks

04
Timeline
Aug 2026 → Apr 2027

Total: 7–8 minutes · 12 slides

2 / 12

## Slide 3

01 · BACKGROUND & MOTIVATION

The Problem I Met

• Built a two-motor robot car — ESP32 + encoder motors, my own hardware
• Observation 1 — motors are the biggest power consumer: the battery drains quickly and much of the energy is wasted rather than converted into motion
• Observation 2 — same PWM ≠ same speed: the two wheels differ by ~5% (wheel encoders) due to motor manufacturing differences → the car drifts off a straight line
• Question raised: does how we command the motors change the energy cost and the accuracy of the movement?

[ photo: the robot car ]
[ plot: rpmL vs rpmR diverging ]

replace before the defense

3 / 12

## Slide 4

01 · BACKGROUND & MOTIVATION

Two Ways to Command a Motor

S-curve motion profiling (open loop)
• Speed follows a smooth, jerk-limited S-shaped reference
• Standard in CNC machines & industrial robots — limits vibration and mechanical stress
Nguyen et al. 2008 · Meckl et al. 1998

PID feedback control (closed loop)
• Continuously corrects PWM from the measured speed error (encoders)
• Most widely used control algorithm in industry
Åström & Hägglund · Mahmud et al. 2020 · Hammoodi et al. 2020

Key structural difference: an open loop sees nothing — a closed loop corrects.

4 / 12

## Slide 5

01 · BACKGROUND & MOTIVATION

Research Gap & Research Question

• Gap — most published comparisons are simulation-based with a single idealised motor: no mismatched motors, no battery, no energy data

Q1 Which strategy completes the task with less energy?

Q2 Which one settles at the target speed faster?

Q3 How much differential can only PID remove?

RESEARCH QUESTION

“How do S-curve open-loop motion profiling and PID closed-loop control compare in the electrical energy consumed and the time taken to complete a speed-change task on a self-built two-motor robot car — and to what extent can PID control additionally suppress the wheel-speed difference that open-loop control cannot solve?”

5 / 12

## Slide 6

02 · EXPERIMENTAL DESIGN

Test Platform & Measurement

HARDWARE

• ESP32 controller
• 2 × JGB37-520B encoder motors (330 counts/rev)
• DRV8833 motor driver

SENSING & LOGGING

• INA226 — bus voltage, current, electrical power
• MPU6050 gyroscope — yaw rate (independent turning check)
• Telemetry @ 10 Hz → CSV: target, rpmL, rpmR, PWM, gyrZ, V, I, P

ALREADY RUNNING
Dual-wheel PID @ 100 ms · anti-windup · optional feed-forward — firmware tested on the real car

TO ADD
On-board S-curve reference generator for the open-loop mode — the same car then runs both strategies

6 / 12

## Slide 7

02 · EXPERIMENTAL DESIGN

Variables & Experimental Protocol

INDEPENDENT
control strategy: S-curve open-loop vs. tuned PID

DEPENDENT
energy (J) · settling time (s) · rpmL−rpmR · yaw rate

CONTROLLED
same car, surface, battery window, speeds · ≥3 repeats

Exp | Design | What it tells us
A | Same speed-change task under both strategies | the energy & time comparison
B | Step-response measurement | system dynamics
C | One-factor-at-a-time PID tuning (Kp, Ki, Kd, FF) | fair tuning — PID not misrepresented
D | Identical S-curve commands vs. per-wheel PID | differential suppression (unique to feedback)
E | Robustness across target speeds (15 / 45 / 90 rpm) | how far conclusions generalise

Extension: PID tracking an S-curve reference — the best of both worlds?

7 / 12

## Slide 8

02 · EXPERIMENTAL DESIGN

Metrics & Hypotheses

HOW THE WINNER IS JUDGED

• Energy = ∫P dt — INA226 power sampled at 10 Hz, integrated over the task
• Settling time — from command until speed stays within a ±5% band of target
• Analysis — mean ± SD over ≥3 repeats, plots in Python / Excel

H1 PID settles faster but may overshoot; the S-curve is smooth by construction

H2 The energy outcome is genuinely open — that is why it must be measured

H3 PID drives rpmL−rpmR → ~0; open-loop leaves ~5% → the car keeps drifting

8 / 12

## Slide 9

03 · FEASIBILITY

Platform & Data Pipeline Already Work

• Hardware: built, wired and running — tested wiring checklist v3.3
• Firmware: PID, telemetry and CSV logging already produce real data (test runs completed in August)
• Remaining build work: one S-curve generator function — weeks, not months
• Low cost, common components → quick repair or replacement
• Supervisor support for the experimental design and review

[ screenshot: real CSV telemetry curve ]

replace before the defense

9 / 12

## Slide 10

03 · FEASIBILITY

Skills, Risks & Backups

Skills in hand: Arduino / ESP32 firmware · Python (pyserial, pandas) · PID theory (Åström & Hägglund)

Risk | Mitigation
INA226 sensor drops out | firmware auto-reconnect + multimeter cross-check
Battery voltage drifts | fixed voltage window per session + voltage logged every sample
Encoder quantisation noise | 100 ms sampling period, low-pass filter, ≥3 repeats
Schedule slip | 6-week buffer before submission

Ethics & safety: low voltage (≤9 V) · bench-tested · new behaviours always wheels-off-ground first

10 / 12

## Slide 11

04 · TIMELINE

Aug 2026 → Apr 2027

Phase | Time | Deliverable
S-curve generator + pilot tests | Aug – mid Sep 2026 | tested open-loop mode
Main experiments A–E + repeats | mid Sep – Nov 2026 | complete CSV dataset
Extension: combined strategy | Nov – Dec 2026 | extra dataset
Data analysis + literature write-up | Dec 2026 – Jan 2027 | figures + review section
Report writing | Jan – Feb 2027 | first full draft
Revision + supervisor review | Mar 2027 | second draft
Buffer + proofreading + submission | Apr 2027 | final report (06/27 series)

Every phase ends with a concrete deliverable — slippage becomes visible early.

11 / 12

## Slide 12

SUMMARY

Expected Contribution

• Same car, same task, two strategies — measured, not assumed
• Two outcomes: the energy–time trade-off + quantified differential suppression that only feedback provides
• Deliverable: evidence-based guidance for battery-powered robots, with an open dataset from a fully documented platform

Thank you — Questions?

12 / 12

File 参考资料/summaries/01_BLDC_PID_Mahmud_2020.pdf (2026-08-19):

01

IPQ 研究项目 · 文献综述总结

PAPER SUMMARY

# 基于 PID 控制器的无刷直流电机（BLDC

# ）转速控制

### Control BLDC Motor Speed using PID Controller

作者：Md Mahmud, S. M. A. Motakabber, A. H. M. Zahirul Alam, Anis Nurashikin Nordin
机构：马来西亚国际伊斯兰大学 电气与计算机工程系
出处：International Journal of Advanced Computer Science and Applications (IJACSA), Vol. 11, No. 3, 2020 方法类别：闭环 PID 控制（电机调速）

核心一句话：在 BLDC 电机中，PID 控制器相比 PI 与模糊控制器具有更小的超调、更快的整定，综合性能最佳。

A Quantitative Comparison of Jerk-Limited S-Curve and PID Control for Smoother and More Energy-Efficient Mobile Robot Motion 2026.07

IPQ 项目 · 论文总结 | BLDC PID 控制 (Mahmud 2020)
Jerk-Limited S-Curve vs. PID Control — Mobile Robot Motion | 第 2 页

## 一、研究背景与问题

在绿色技术与清洁能源的大趋势下，电动机是把电能转换为机械能的核心装置。其中无刷直流电机（ BLDC）因维护成本低、结构紧凑、效率高（常超过 95%），被广泛用于电动汽车、变频驱动等工业场景。 然而，BLDC 的性能高度依赖其控制电路，设计高性能控制电路一直是研究难点。

论文指出：传统的 PI/PID 控制器虽然结构简单、易于实现，但参数整定并不简单；尤其在负载波动、非 线性因素存在时，难以在所有工况下都获得最优响应。本文的目标是通过改进的 PID 控制方案实现对 BLDC 电机转速的有效调节，并在负载变化时维持恒定转速。

## 二、核心方法

### 1. 系统结构

采用双闭环控制：内环用于检测电源极性与换相，外环用于转速控制。系统包含 DC 电源、PID 控制器、 逆变器（DC→AC，因 BLDC 需类三相交流电压）、霍尔传感器（检测转子位置）以及电机本体。

### 2. PID 控制器建模

PID 传递函数为：G(s) = Kp + Ki/s + Kd·s。控制律 U(t) = Kp·e(t) + Ki∫e(t)dt + Kd·de(t)/dt。本文所用 关键参数：

方法 | Kp | Ki | Kd
PID（本文） | 100 | 0.5 | 500

### 3. 仿真平台

基于 MATLAB/Simulink 搭建三相 BLDC 电机控制系统完整模型，包含解码器真值表（顺时针/逆时针换相） 、反电动势（BEMF）生成、逆变器开关逻辑等，并在 2500 rpm 参考转速下进行空载测试。

## 三、主要结果

在 2500 rpm 参考转速、空载条件下，对 PI、PID、模糊逻辑三种控制器进行对比，关键性能指标如下：

指标 | PI 控制器 | PID 控制器 | 模糊控制器
整定时间 | 15.20 ms | 约 18 ms | 9.2 ms
超调量 | 32.67% | 0.4% | 30.92%
欠调量 | 1.68% | 1.9% | 3.2%
转换速率 | 621.35 ms | 92.27 ms | 598.15 ms
预调节 | 0.66% | 2.5% | 0.67%

IPQ 项目 · 论文总结 | BLDC PID 控制 (Mahmud 2020)
Jerk-Limited S-Curve vs. PID Control — Mobile Robot Motion | 第 3 页

可见 PID 控制器的超调量（0.4%）远低于 PI（32.67%）和模糊（30.92%），转换速率也明显更优。约 0.018 s 后电机即稳定在 2500 rpm；电磁转矩、三相定子电流、反电动势均在约 0.030 s 后稳定。

## 四、结论与对本研究的启示

- 核心结论：在所对比的三种控制器中，PID 控制器为 BLDC 电机提供了最佳综合控制性能。
- 方法局限：仅空载仿真，未在变负载、变惯量工况下验证；参数为手工给定，未给出系统化整定方 法。
- 对本研究的关联：本文属于"PID 控制器在电机运动控制中的经典应用与性能上限"的代表性工作。 在我们的 IPQ 研究中，PID 是对照基线（baseline）——它代表了"传统反馈控制"路径；而 S 曲线属于" 前馈轨迹规划"路径。该论文提供的超调、整定时间等量化指标，可作为我们评估 PID 路径平滑性与 能耗时的参照。

## 五、文献信息

Mahmud, M., Motakabber, S. M. A., Alam, A. H. M. Z., & Nordin, A. N. (2020). Control BLDC Motor Speed using PID Controller. International Journal of Advanced Computer Science and Applications (IJACSA), 11(3), 477–481.

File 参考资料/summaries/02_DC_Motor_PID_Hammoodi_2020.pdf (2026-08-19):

02

IPQ 研究项目 · 文献综述总结

PAPER SUMMARY

# 基于 PID 控制与 MATLAB/Simulink 的

# 直流电机调速系统设计与实现

### Design and Implementation Speed Control System of DC Motor based on PID Control and Matlab Simulink

作者：Salman Jasim Hammoodi, Kareem Sayegh Flayyih, Ahmed Refaat Hamad
机构：Middle Technical University / Southern Technical University（伊拉克）
出处：International Journal of Power Electronics and Drive Systems (IJPEDS), Vol. 11, No. 1, 2020, pp. 127–134 方法类别：闭环 PID 调速 + PWM 斩波电路

核心一句话：用 PID + 斩波晶体管电路构建直流电机闭环调速系统，可在负载扰动下自动维持转速恒定。

A Quantitative Comparison of Jerk-Limited S-Curve and PID Control for Smoother and More Energy-Efficient Mobile Robot Motion 2026.07

IPQ 项目 · 论文总结 | DC电机 PID 调速 (Hammoodi 2020)
Jerk-Limited S-Curve vs. PID Control — Mobile Robot Motion | 第 2 页

## 一、研究背景与动机

工业中大部分电机直接由电网供电，其行为取决于负载特性：轻载时转速高、转矩小；重载时转速低、 转矩大。交流变频器成本低廉，但直流电机的可调速驱动器价格昂贵，许多需要它的行业难以负担。本 文目标是设计一套经济可行、易于实现、可移植到任意 DC 电机的自有 PID 调速系统。

## 二、核心方法

### 1. DC 电机建模

将电机分为电气部分（电枢：电阻 R、电感 L、反电动势 Kb）与机械部分（转子：转动惯量 J、粘性摩擦 系数 b、转矩 T）。关键方程：

V_dc = E_am + I_am·R_a + V_brush； E_am = K_m·I_f·ω； T = P_out/ω = K_m·I_a·I_f

### 2. PID 控制器

控制器接收输入信号与测速发电机输出之差作为误差，经放大后送入被控对象。PID 传递函数：Gc(s) = Kp + Kd·s + Ki/s。论文给出四种 PID 形式：理想型、串联型、并联型、工业型，并提及 Ziegler–Nichols 整定法则。

### 3. 仿真实现

使用 MATLAB/Simulink 搭建他励直流电机模型，由 DC 源经 GTO-1 晶闸管斩波电路供电。PID 参数取 P = 4, I = 0.01, D = 0.5。系统通过转速闭环：测量实际转速，与参考转速比较，确定所需的电枢电流。

## 三、主要结果

- 转速响应（wr 相对参考转速）：PID 控制下响应快速，能迅速跟踪参考值。
- 负载转矩（TL）与电枢电流：均展现出快速响应特性，验证了扰动抑制能力。
- PWM 信号：给出了 GTO-1 晶闸管的触发波形，形成完整的斩波驱动链路。

结论：PID 控制器在伺服机构或调节系统中均能提供良好的动态行为；但不同厂商的 PID 算法实现存在 差异，更换控制器时必须重新计算参数。

## 四、关键洞察与对本研究的启示

- 双时间常数模型：论文用电气时间常数 Ta 与机电时间常数 Tem 描述电机（Ta ≪ Tem），简化后 传递函数 ω(s)/Va(s) = (1/Km)/[(1+sTem)(1+sTa)]，是建模移动机器人驱动轮电机的经典起点。
- PID + PWM 斩波是移动机器人底层驱动的事实标准方案，本文提供了该方案的完整 Simulink 实现 ，可作为本研究"PID 基线"的工程参考。
- 局限：论文聚焦"转速跟踪"而非"轨迹平滑"——它能让转速快速跟上阶跃参考，但参考本身若不光 滑（阶跃），仍会产生冲击（jerk）与机械振动。这正是本研究引入 S 曲线前馈规划要解决的核心问 题。

IPQ 项目 · 论文总结 | DC电机 PID 调速 (Hammoodi 2020)
Jerk-Limited S-Curve vs. PID Control — Mobile Robot Motion | 第 3 页
- 桥接点：本文回答"如何快速到达目标转速"；本研究要回答"如何让到达目标转速的过程更平滑、 更节能"——PID 解决"快与准"，S 曲线解决"稳与省"。

## 五、文献信息

Hammoodi, S. J., Flayyih, K. S., & Hamad, A. R. (2020). Design and implementation speed control system of DC Motor based on PID control and Matlab Simulink. International Journal of Power Electronics and Drive Systems (IJPEDS), 11(1), 127–134. DOI: 10.11591/ijpeds.v11.i1.pp127-134

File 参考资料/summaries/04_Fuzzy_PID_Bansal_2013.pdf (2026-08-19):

04

IPQ 研究项目 · 文献综述总结

PAPER SUMMARY

# 基于模糊 PID 控制器的直流电机调速

### Speed Control of DC Motor Using Fuzzy PID Controller

作者：Umesh Kumar Bansal, Rakesh Narvey
机构：M.I.T.S. Gwalior 电气工程系（印度）
出处：Advance in Electronic and Electric Engineering, Vol. 3, No. 9, 2013, pp. 1209–1220 方法类别：模糊自整定 PID（智能控制）

核心一句话：用模糊逻辑在线自整定 PID 三个增益，使 DC 电机在动态响应与稳态精度上均优于传统定参 PID。

A Quantitative Comparison of Jerk-Limited S-Curve and PID Control for Smoother and More Energy-Efficient Mobile Robot Motion 2026.07

IPQ 项目 · 论文总结 | 模糊PID调速 (Bansal 2013)
Jerk-Limited S-Curve vs. PID Control — Mobile Robot Motion | 第 2 页

## 一、研究背景

DC 电机因结构简单、可靠性高、调速性能优越，长期是工业、机器人与家电的骨干。性能电机驱动系统 必须具备良好的动态转速跟踪与负载调节能力。PID 控制器占工业过程控制应用的 95% 以上，但在 DC 电机中，饱和、摩擦等非线性特性会显著降低传统 PID 的性能，且精确的非线性模型难以获得。

论文引入模糊逻辑控制（FLC）——它不依赖精确系统模型，仅根据人工经验的"IF-THEN"规则即可对复 杂非线性系统实施控制，是与传统控制互补的新思路。

## 二、核心方法：模糊自整定 PID

### 1. DC 电机建模

建立电枢电压方程与转矩平衡方程，经拉氏变换与简化（电气时间常数 Ta ≪ 机电时间常数 Tem），得 到传递函数：

ω(s)/Va(s) = (1/Km) / [(1+s·Tem)(1+s·Ta)]

电机参数：Ra=0.5Ω, La=0.02H, Va=200V, Jm=0.1 kg·m², Bm=0.008, K=1.25, 额定 1500 rpm。

### 2. 模糊控制器结构

采用双输入三输出结构：

- 输入：转速误差 eω(k) 与误差变化率 deω(k)。
- 输出：PID 的三个增益 Kp、Ki、Kd。
- 模糊化：三角隶属函数，论域分为 7 档（NL/NM/NS/ZE/PS/PM/PL），零点附近更密以提高稳态精 度。
- 规则库：每个增益 25 条规则（5×5），形如"IF eω is NL AND deω is NL THEN Kp is PV"。
- 推理与解模糊：Max-product 推理，输出由模糊变量还原为精确量。

### 3. 自整定原理

核心是找出 PID 三参数与 (e, de) 之间的模糊关系，在不同误差状态下实时修改三参数，使控制对象兼顾 动态与稳态性能。稳态附近细化隶属函数以获得精细控制分辨率，远离零点处展宽以获得快速响应。

## 三、主要结果

通过 MATLAB/Simulink 仿真对比传统定参 PID与模糊自整定 PID，结论：

性能维度 | 传统 PID | 模糊自整定 PID
动态响应 | 一般 | 更好
上升时间 Tr | 较长 | 更短
整定时间 | 较长 | 更短

IPQ 项目 · 论文总结 | 模糊PID调速 (Bansal 2013)
Jerk-Limited S-Curve vs. PID Control — Mobile Robot Motion | 第 3 页
性能维度 | 传统 PID | 模糊自整定 PID
最大超调 Mp | 较大 | 更小
稳态误差 SSE | 较大 | 更小，精度更高

论文总结：模糊自整定 PID 同时具备PID 的精确性与模糊控制的灵活性，在瞬态与稳态两方面均优于传 统 PID。

## 四、对本研究的启示

- 第三条对照路径：除 PID 与 S 曲线外，模糊自整定 PID 是"反馈控制"家族中性能更强的成员。本研 究若仅对比 PID vs S 曲线，可能被质疑"PID 整定不够好"；引入模糊 PID 可作为强化 baseline，使 S 曲 线的优势结论更有说服力。
- 仍然属于"反馈"范式：模糊 PID 本质仍是"误差驱动的反馈控制"，它优化的是"如何更快消除误差" ，而不改变参考轨迹本身的平滑性。因此它无法解决"阶跃参考带来的初始 jerk"问题——这正是 S 曲 线（前馈规划）的不可替代价值。
- 方法借鉴：模糊规则的"零点附近细化"思想，与 S 曲线"在加减速阶段细化时间"异曲同工，都强调 在关键过渡区提升分辨率。本研究可在轨迹规划层借鉴这种"非均匀精度"思想。
- 局限：依赖专家经验设计规则库，可移植性受限；论文为纯仿真，无能耗分析。

## 五、文献信息

Bansal, U. K., & Narvey, R. (2013). Speed Control of DC Motor Using Fuzzy PID Controller. Advance in Electronic and Electric Engineering, 3(9), 1209–1220. ISSN 2231-1297.

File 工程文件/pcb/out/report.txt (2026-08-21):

IPQ CARRIER DRC-lite report
==================================================
焊盘 93，过孔 27，走线段 119

[PASS] 无间距/环宽/板边错误

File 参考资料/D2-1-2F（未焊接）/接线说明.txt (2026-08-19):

这个不需要接pwm（en）引脚，直接接in引脚

VM是供电引脚

*为了是电机正常工作，STBY需要接3.3V或者5V的高电平

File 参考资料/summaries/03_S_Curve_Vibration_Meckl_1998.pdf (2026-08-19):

03

IPQ 研究项目 · 文献综述总结

PAPER SUMMARY

# 面向最小残余振动的 S 曲线运动轨迹优化

### Optimized S-Curve Motion Profiles for Minimum Residual Vibration

作者：Peter H. Meckl, Peter B. Arestides, Matthew C. Woods
机构：School of Mechanical Engineering, Purdue University（美国）
出处：Proceedings of the American Control Conference, Philadelphia, PA, June 1998, pp. 2627–2631 方法类别：S 曲线 + 频域优化（减振）

核心一句话：通过频域分析最优选择 S 曲线的"加速上升时间"，使残余振动降低近一个数量级，且对频率不确定 性具有鲁棒性。

A Quantitative Comparison of Jerk-Limited S-Curve and PID Control for Smoother and More Energy-Efficient Mobile Robot Motion 2026.07

IPQ 项目 · 论文总结 | S曲线减振优化 (Meckl 1998)
Jerk-Limited S-Curve vs. PID Control — Mobile Robot Motion | 第 2 页
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

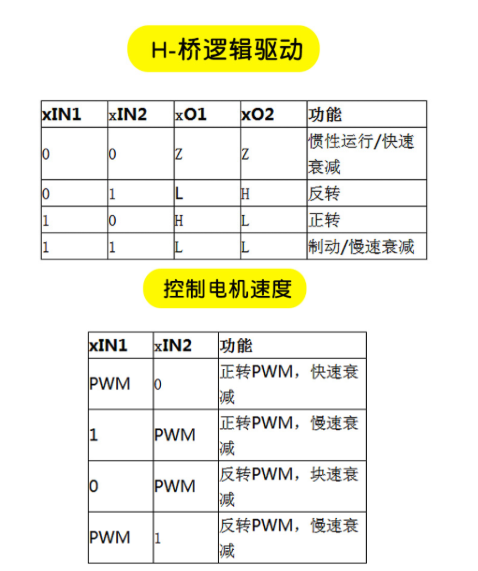
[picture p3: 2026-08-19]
参考资料/D2-1-2F（未焊接）/真值表.png

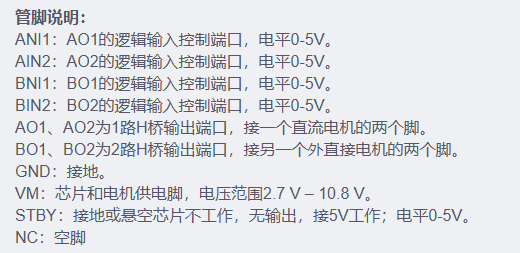
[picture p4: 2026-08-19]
参考资料/D2-1-2F（未焊接）/引脚说明.png

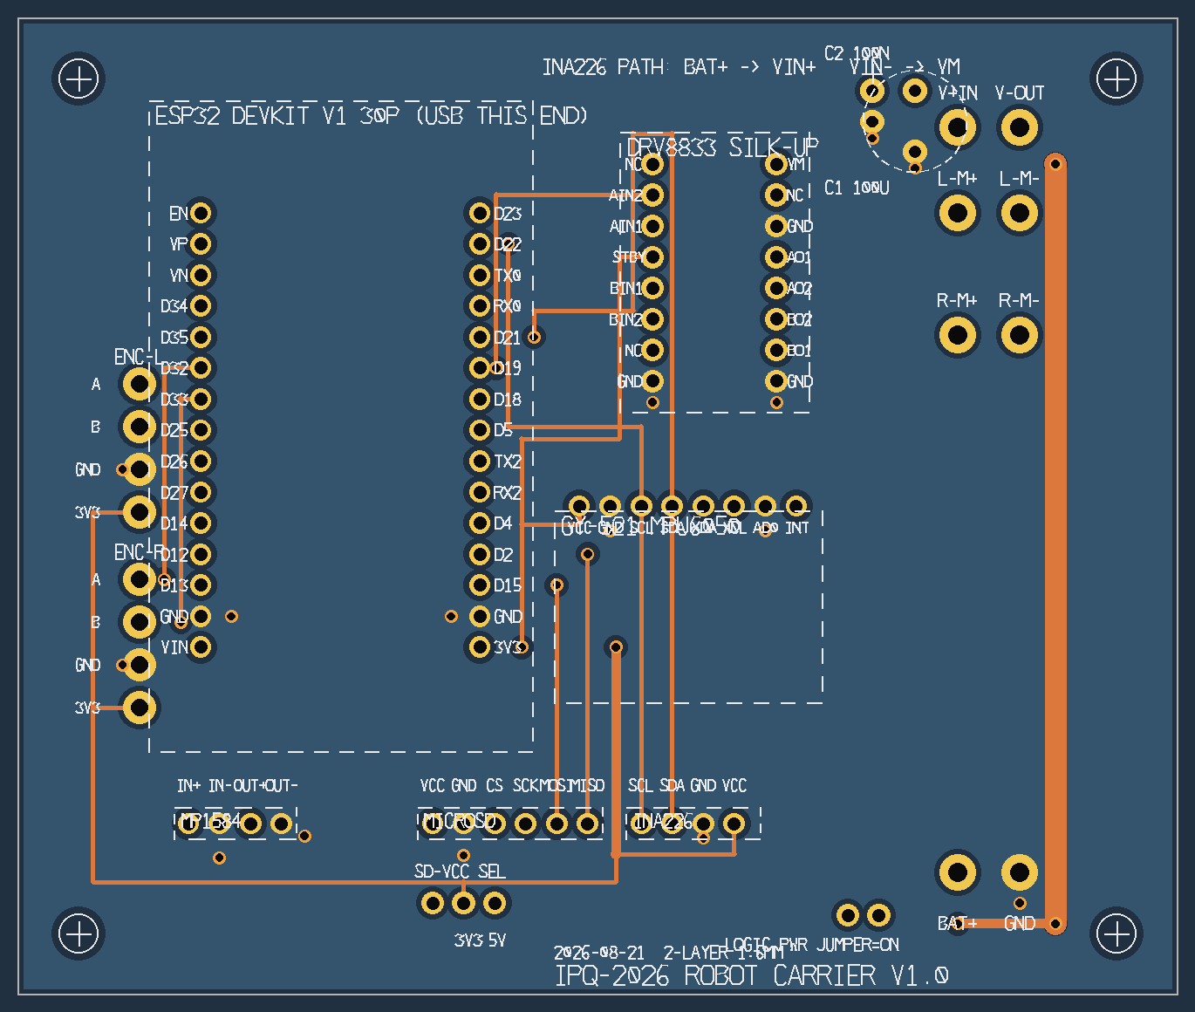
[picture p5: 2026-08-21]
工程文件/pcb/out/preview_bottom.png

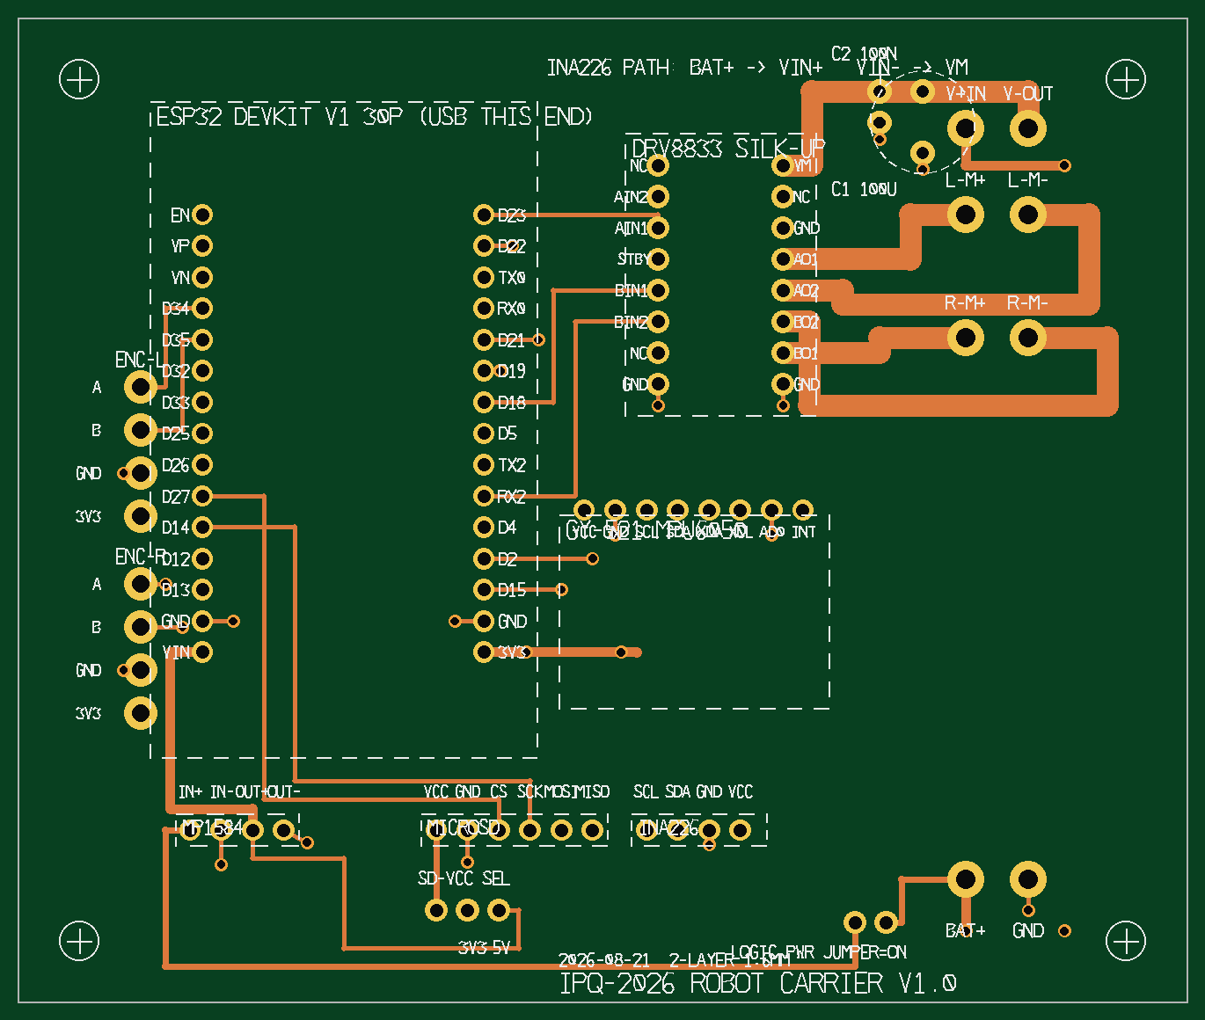
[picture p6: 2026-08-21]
工程文件/pcb/out/preview_top.png

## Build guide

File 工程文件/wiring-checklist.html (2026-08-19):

# IPQ 移动机器人 · 逐线接线清单共 42 根 · 接一根勾一根

ESP32 DevKit V1 · DRV8833 · JGB37-520B×2 · INA226 · MPU6050 · microSD · MP1584 定压 5V · 2×18650 (7.4V)

版本 v3.3 日期 2026-08-17 已核对 DRV8833 厂家资料 电源 2S 7.4–8.4V · 定压 MP1584

已接线0/ 42

↺ 重置全部

## ⚠ 接线前的四个关键说明

① 电池线「一分为二」怎么做到？
电池的 (+) 要同时供给 INA226 VIN+ 和 MP1584 IN+；(−) 要同时供给 DRV8833 GND 和 MP1584 IN−。物理实现二选一：
方式 A（推荐）：把两根线的铜端并排一起压进同一个螺丝端子——电池(+)和去 MP1584 的红线同压 INA226 的 VIN+ 端子；电池(−)和去 MP1584 的黑线同压 DRV8833 的 GND 端子。逻辑电流不会流过 INA226 分流电阻，测量仍然只含电机 ✅
方式 B：在电池引线上焊接 Y 形分头，热缩管/胶带绝缘。
❌ 不许把 7.4V 动力电放上面包板轨道；❌ 电机电流路径（线 1/2/3/27–30）不经过面包板。

② microSD 模块的 VCC 电压（线 15）先看板子再接：
板上有 AMS1117 稳压器芯片 + 电平转换芯片 → VCC 接 5V（从 MP1584 OUT+ 引一根，不占红轨）；
板上没有稳压器、直通 3.3V → VCC 接面包板红轨 (3.3V)。
接错电压轻则不读卡，重则烧卡。

③ 面包板两轨定义：
红轨 ⊕ = ESP32 输出的 3.3V（源头是 ESP32 的 3V3 引脚，即线 8）
蓝轨 ⊖ = GND 汇流（源头是 ESP32 的 GND 引脚，即线 9）
⚠ 先用万用表确认你的面包板轨道中段没有断开（红轨首尾孔量通断），断了就拿线桥接。

④ GPIO 12 与 GPIO 0 禁用（启动 strapping 脚）：
GPIO 12（丝印 D12）在开机瞬间若是高电平，ESP32 会把 flash 电压切到 1.8V → 反复重启、进不了系统。CS 平时就是高电平，接 12 必定无法开机；SD 模块其它线（带上拉）同样会踩雷。GPIO 0 则影响烧录模式，也不要占用。
→ 因此 CS 从 GPIO 13 改到 GPIO 27（13 本身安全，但它的插孔紧挨着 D12，容易数错一格误插）。

## 🎨 线色约定（强烈建议遵守）

颜色统一，排查问题时能省一半时间。没条件全遵守时，至少保证：红=正、黑=地。

红 = 电池+ / 3.3V

黑 = GND

黄 = 编码器 A 相

绿 = 编码器 B 相

蓝 = I²C SDA / 左电机

白 = I²C SCL / 右电机

紫 = PWM 调速

橙 = 方向控制

## 🔌 全部 42 根线 · 端到端清单

按组排列，组内顺序即推荐施工顺序：先电源轨 → 再信号 → 最后电机动力。勾选状态自动保存在本浏览器。

✓ | # | 起点（模块 · 端口） | | 终点（模块 · 端口） | 线色 | 用途 / 备注

## ✅ 全部接完后的上电快检

- 万用表蜂鸣档：电池(+) ↔ 各模块 VCC 不应短路到 GND（红轨 ↔ 蓝轨应不通）
- 电池电压 ≤ 8.4V（2S 满电）；MP1584 OUT+ 对 GND ≈ 5V（定压版只验证不调）
- DRV8833：STBY 已接红轨、VM 上量到电池电压（经 INA226）
- 先拔电机线，只上逻辑电：ESP32 跑 I²C 扫描，应出现 0x40（INA226）和 0x68（MPU6050）
- I²C 通了再接电机：PWM 30% 低速试转，方向不对就对调 AO1/AO2（或 BO1/BO2）
- 烧录程序失败时：拔掉 microSD 模块再烧（GPIO 2 是启动脚，SD 卡会干扰进烧录模式）
- 任何线都不得接 GPIO 12 / GPIO 0（启动脚，接高会无法开机或无法烧录，见说明④）

IPQ-2026 · 逐线清单 v3.3 · 与 wiring.html (v3.2) 配套 · 2026-08-17

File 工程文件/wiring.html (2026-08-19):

# IPQ 移动机器人 · 接线方案 v3DRV8833 + 2S 7.4V

ESP32 DevKit V1 · JGB37-520B 编码电机 ×2 · DRV8833 · INA226 · MPU6050 · microSD

项目 IPQ-2026 版本 v3.2 (厂家资料核对 · CS→27 · 右编码→32/33) 日期 2026-08-17 主控 ESP32 DevKit V1 (30针) 电源 2×18650 串联 7.4–8.4V

## 📚厂家资料核对 基于 D2-1-2F DRV8833 模块资料包

本方案已对照 DRV8833 模块的厂家资料（引脚说明、真值表、使用说明、示例代码）逐项核对。丝印名称、真值表、电压范围均以厂家资料为准。

项目 | 厂家资料原文 | 本方案采用
VM 电压范围 | "2.7V－10.8V" / "VM 接 12V 以内电源" | 2×18650 串联 7.4–8.4V ✓
使能脚 | "STBY：接地或悬空芯片不工作，无输出，接 5V 工作" | STBY → ESP32 3V3
PWM 接法 | "这个不需要接 pwm（en）引脚，直接接 in 引脚" | PWM 直接给 AIN2/BIN2
真值表 | 00=滑行 / 01=反转 / 10=正转 / 11=刹车 | 完全采用
输出端丝印 | AO1/AO2（1路H桥）、BO1/BO2（2路H桥） | 已采用 AO/BO 命名

✓ 核对结论：核心接法（PWM 直接给 IN、2S 电池、STBY 拉高）与厂家资料完全一致。仅丝印名称按实物修正（OUT1-4 → AO1/AO2/BO1/BO2，nSLEEP → STBY）。

## 🔄变更摘要 vs 之前 TB6612 + 3S 版本

从 TB6612 换成 DRV8833，并相应调整了电源与控制引脚。以下是关键变化点：

项目 | 旧 (TB6612) | 新 (DRV8833)
电池组 | 3 串 11.1V (满电 12.6V) | 2 串 7.4V (满电 8.4V)
原因 | DRV8833 的 VM 上限 10.8V，12.6V 会烧片；改 2S 后电机仍可正常工作
使能脚 | STBY (拉高) | nSLEEP (拉高)
逻辑供电 | VCC | VCC (3.3V 即可)
PWM 调速脚 | PWMA / PWMB (独立) | AIN2 / BIN2 直接 PWM
方向控制 | AIN1/AIN2 两脚（与 TB6612 相同的真值表）

⚠ 三个必记要点：

1. 电池改 2 串（满电 8.4V），在 DRV8833 的 10.8V 安全区内
2. DRV8833 的 nSLEEP 必须接 3V3，不接芯片一直休眠、电机不转
3. INA226 串联在「电池正极 → DRV8833 VM」之间，像电流表一样串进去

## 🟠一、电源系统 动力回路 + 逻辑回路

两条独立电源回路：动力回路（电池→INA226→DRV8833→电机）和 逻辑回路（电池→MP1584→ESP32/传感器）。两路共用电池，但 GND 必须连通。

### 动力回路（被 INA226 测量）

起点 | 起点端口 | → | 终点 | 终点端口 | 说明
2×18650 电池盒 | (+) 红线 | → | INA226 | VIN+ | 电流流入
INA226 | VIN− | → | DRV8833 | VM | 电流流出 → 驱动
2×18650 电池盒 | (−) 黑线 | → | DRV8833 | GND | 接全局共地

### 逻辑回路（不经 INA226）

起点 | 起点端口 | → | 终点 | 终点端口 | 说明
2×18650 电池盒 | (+) 红线 | → | MP1584 | IN+ | 7.4V 输入
2×18650 电池盒 | (−) 黑线 | → | MP1584 | IN− | 共地
MP1584 | OUT+ (5V 定压版) | → | ESP32 | VIN / 5V | ⭐ 定压输出，直接用
MP1584 | OUT− | → | ESP32 | GND | 共地

✓ 定压版 MP1584：输出已固定 5.0V，无需调试，接上即用。

共地原则：电池(−) = MP1584 IN− = DRV8833 GND = ESP32 GND = 所有传感器 GND，全部连通。

## 🟦二、ESP32 ↔ DRV8833 电机驱动 驱动 2 个 JGB37-520B · 厂家丝印

✓ 已核对厂家资料：本模块丝印为 STBY / VM / AIN1 / AIN2 / BIN1 / BIN2 / AO1 / AO2 / BO1 / BO2 / GND。无 VCC、无 nSLEEP、无 EN 引脚（模块内部已处理）。

### 控制信号真值表（厂家资料原文）

0 / 0

滑行 Coast
(惯性/快速衰减)

0 / 1

反转

1 / 0

正转

1 / 1

刹车 Brake
(短路制动)

PWM 调速方法（厂家推荐）：固定 IN1=1（正转），在 IN2 上给 PWM，占空比 0–100% 控制转速。厂家接线说明："不需要接 pwm（en）引脚，直接接 in 引脚"。

### 控制信号接线（ESP32 → DRV8833）

ESP32 端口 | → | DRV8833 模块丝印 | 功能
GPIO 23 | → | AIN1 | 左电机方向控制
GPIO 19 | → | AIN2 | 左电机 PWM 调速 ⭐
GPIO 18 | → | BIN1 | 右电机方向控制
GPIO 16 | → | BIN2 | 右电机 PWM 调速 ⭐
3V3 | → | STBY | ⭐ 必接！厂家原文："接 5V 工作，接地或悬空不工作"
GND | → | GND | 共地

注意：本模块无 VCC 引脚——逻辑供电已由 VM 通过内部稳压提供，不需要单独接 3.3V/5V 给逻辑侧。只需接 VM（动力）+ STBY（使能）+ GND + 4 个 IN 控制脚。

### 动力电源接线

来源 | → | DRV8833 模块丝印 | 说明
INA226 VIN−（来自电池+） | → | VM | 电机供电 7.4–8.4V（厂家："2.7–10.8V"）
电池(−) | → | GND | 共地

### 电机输出（DRV8833 → 电机，厂家丝印）

DRV8833 模块丝印 | → | 电机 | 说明（厂家原文）
AO1 | → | 左电机 JGB37-520B | "AO1、AO2 为 1 路 H 桥输出"——接电机两端
AO2 | → | 左电机 JGB37-520B | 接反则反转，对调即可
BO1 | → | 右电机 JGB37-520B | "BO1、BO2 为 2 路 H 桥输出"
BO2 | → | 右电机 JGB37-520B | 接反则反转，对调即可

## 🟢三、ESP32 ↔ 编码器 JGB37-520B 自带霍尔编码器

每个电机有 6 根线：电机 2 根 + 编码器 4 根。编码器是推挽输出，任意 GPIO 都可接。左编码器用 input-only 脚 34/35；右编码器 v3.3 起改用普通脚 32/33，功能完全相同。

电机编码器线 | 线色（常见） | → | ESP32 端口 | 功能
左电机编码器
VCC | 红 | → | 3V3 | 编码器供电
GND | 黑 | → | GND
A 相 | 黄 | → | GPIO 34 ⭐ | A 相脉冲（input-only）
B 相 | 绿 | → | GPIO 35 ⭐ | B 相脉冲（input-only）
右电机编码器
VCC | 红 | → | 3V3
GND | 黑 | → | GND
A 相 | 黄 | → | GPIO 32 | v3.3 改（原 36/VP），普通脚功能相同
B 相 | 绿 | → | GPIO 33 | v3.3 改（原 39/VN）

⚠ 线色因厂家而异：请以你买到的电机标签为准（通常是 红=VCC、黑=GND、黄=A、绿=B，可能还有白线备用）。

## 🟣🟡四、ESP32 ↔ INA226 + MPU6050 I²C 并联共用总线

两个传感器 共用同一条 I²C 总线，地址不冲突（INA226=0x40，MPU6050=0x68）。SDA/SCL 分别并联接到同一对 ESP32 引脚。

ESP32 端口 | → | INA226 (CJMCU-226) | → | MPU6050 (GY-521) | 功能
GPIO 21 (SDA) | → | SDA | → | SDA | I²C 数据线（并联）
GPIO 22 (SCL) | → | SCL | → | SCL | I²C 时钟线（并联）
3V3 | → | VCC | → | VCC | 供电
GND | → | GND | → | GND | 共地

INA226 电流采样端子（独立接动力回路，见第一节）：VIN+ ← 电池(+)，VIN− → DRV8833 VM。这是核心串联接法。

MPU6050 提示：板载已有 4.7kΩ 上拉电阻，I²C 总线无需额外加上拉。AD0 接 GND（或留空）→ 地址 0x68。

## 🔴五、ESP32 ↔ microSD 模块 SPI 接口，高频数据记录

使用 ESP32 的 VSPI 默认引脚组，Arduino-ESP32 的 SD.begin() 直接可用。

ESP32 端口 | → | microSD 模块 | 功能
GPIO 14 (HS2_CLK) | → | SCK / CLK | SPI 时钟
GPIO 15 (HS2_CMD) | → | MOSI / DI | 主出从入
GPIO 2 (HS2_DATA0) | → | MISO / DO | 主入从出
GPIO 27 | → | CS | 片选 ⚠ 避开禁用的 GPIO 12（启动脚，接高会无法开机）
3V3 或 5V | → | VCC | ⚠ 看模块标注：5V 兼容版接 5V，纯 3.3V 版接 3V3
GND | → | GND | 共地

⚠ GPIO 12 / GPIO 0 禁用：两者均为启动 strapping 脚。GPIO 12 开机瞬间为高电平会把 flash 电压切到 1.8V，导致 ESP32 反复重启无法开机——CS 平时为高电平，接 12 必出问题。CS 因此从 GPIO 13 改到 GPIO 27（13 本身安全，但插孔紧邻 D12，易误插）。

## 🖼完整端到端电路示意图 端口名称标注

下图展示所有模块的真实电气连接关系，每一根线都标注了端口名称。

╔═══════════════════════════════════════════════════════════════════════╗
║                        IPQ 机器人 · 整体接线图                          ║
║                  ESP32 + DRV8833 + 2×18650 (7.4V)                     ║
╚═══════════════════════════════════════════════════════════════════════╝

【动力回路 — 电机供电，被 INA226 测量】
┌─────────────┐
│ 2×18650 电池 │ (+红)──────►[INA226 VIN+]──[INA226 VIN−]──►┐
│   7.4~8.4V   │                                              ▼
│              │                                    ┌─────────────────────┐
│              │                                    │   DRV8833          │
│              │                                    │   VM  ◄────────────┤  (来自 INA226 VIN−)
│              │                                    │                     │
│              │                                    │   AO1 ──► 左电机(M+)
│              │                                    │   AO2 ──► 左电机(M−)
│              │                                    │   BO1 ──► 右电机(M+)
│              │                                    │   BO2 ──► 右电机(M−)
│              │ (−黑)────────────────────────────► │   GND             │
└─────────────┘                          ┌         └─────────────────────┘
                                         │                  ▲
                                         │                  │
                                    (所有 GND 共地)     │
                                         │                  │
【逻辑回路 — 给 ESP32/传感器 5V，不经 INA226】        │
┌─────────────┐                          │                  │
│ 2×18650 电池 │ (+)──►[MP1584 IN+]       │                  │
│              │      MP1584 定压5V输出    │                  │
│              │      MP1584 OUT+ ──► ESP32 VIN              │
│              │      MP1584 OUT− ──► ESP32 GND ──┐          │
│              │ (−)─────────────────────────────┤          │
└─────────────┘                                  │          │
                                                  ▼          │
╔══════════════════════════════════════════════════════════╤══════════╗
║                     ESP32 DevKit V1                      │          ║
║                                                          │  信号侧  ║
║   VIN(5V) ◄──── MP1584 OUT+                              │          ║
║   GND    ◄──── MP1584 OUT− (与动力GND共地)                │          ║
║                                                          │          ║
║   3V3 ─────┬─────► DRV8833 STBY      (使能,必接!)     │          ║
║            ├─────► 编码器×2 VCC                        │          ║
║            ├─────► INA226 VCC                          │          ║
║            ├─────► MPU6050 VCC                         │          ║
║            └─────► microSD VCC                         │          ║
║            (本模块无 VCC——逻辑电由 VM 内部供给)     │          ║
║                                                          │          ║
║   GPIO 23 ──────► DRV8833 AIN1   (左电机方向)         │          ║
║   GPIO 19 ──────► DRV8833 AIN2   (左电机PWM)          │          ║
║   GPIO 18 ──────► DRV8833 BIN1   (右电机方向)         │          ║
║   GPIO 16 ──────► DRV8833 BIN2   (右电机PWM)          │          ║
║                                                          │          ║
║   GPIO 34 ◄───── 左编码 A相(黄) ⭐input-only            │          ║
║   GPIO 35 ◄───── 左编码 B相(绿) ⭐input-only            │          ║
║   GPIO 32 ◄───── 右编码 A相(黄) （v3.3改）            │          ║
║   GPIO 33 ◄───── 右编码 B相(绿) （v3.3改）            │          ║
║                                                          │          ║
║   GPIO 21 (SDA) ─┬─► INA226 SDA                        │          ║
║                  └─► MPU6050 SDA   (I²C并联)            │          ║
║   GPIO 22 (SCL) ─┬─► INA226 SCL                        │          ║
║                  └─► MPU6050 SCL   (I²C并联)            │          ║
║                                                          │          ║
║   GPIO 14 ──────► microSD SCK                          │          ║
║   GPIO 15 ──────► microSD MOSI                         │          ║
║   GPIO  2 ◄───── microSD MISO                          │          ║
║   GPIO 27 ──────► microSD CS                           │          ║
║                                                          │          ║
║   GND ─────┬─────► DRV8833 GND                          │          ║
║            ├─────► 编码器 GND                            │          ║
║            ├─────► INA226 GND                           │          ║
║            ├─────► MPU6050 GND                          │          ║
║            ├─────► microSD GND                          │          ║
║            └─────► (接入全局共地线)                       │          ║
╚════════════════════════════════════════════════════════════════════╝

【全局共地】  电池(−) = MP1584 IN− = DRV8833 GND = ESP32 GND = 所有传感器GND
                         └────────────── 全部连通 ──────────────┘

## 📋ESP32 引脚分配总表 DRV8833 版，无冲突

GPIO 2

→ microSD

MISO

GPIO 27

→ microSD

CS

GPIO 14

→ microSD

SCK

GPIO 15

→ microSD

MOSI

GPIO 16

→ DRV8833 BIN2

右电机 PWM ⭐

GPIO 18

→ DRV8833 BIN1

右电机方向

GPIO 19

→ DRV8833 AIN2

左电机 PWM ⭐

GPIO 21

→ INA226+MPU6050

I²C SDA

GPIO 22

→ INA226+MPU6050

I²C SCL

GPIO 23

→ DRV8833 AIN1

左电机方向

GPIO 34 ⭐

← 左编码 A 相

input-only

GPIO 35 ⭐

← 左编码 B 相

input-only

GPIO 32

← 右编码 A 相

普通脚（v3.3，原36）

GPIO 33

← 右编码 B 相

普通脚（原39）

⭐ = ESP32 的 input-only 引脚（现仅左编码器用的 34/35）；右编码器 v3.3 起用普通脚 32/33，功能相同。VP(36)/VN(39) 已空出备用。

## ✅上电检查清单 接线后必做

- 用万用表测电池盒电压，确认 ≤ 8.4V（满电两串），超过先放电
- MP1584 定压版，确认接线极性正确即可（OUT+→VIN、OUT−→GND），无需调压
- DRV8833 的 STBY 已接 3V3（厂家原文："接 5V 工作，悬空不工作"——最容易忘的一脚）
- INA226 的 VIN+ 接电池正极、VIN− 接 DRV8833 VM（电流串联，方向不能反，反了测负值）
- 所有 GND 连通（用通断档量：电池(−) ↔ ESP32 GND ↔ DRV8833 GND）
- 电池正极没有短路到 GND（通断档量应不通）
- ESP32 的 VIN 上是 5V 不是 12V（量一下！）
- 先拔掉电机线，通电测 I²C：能扫到 0x40 (INA226) 和 0x68 (MPU6050)
- 最后接电机，用低 PWM（30%）试转，确认方向正确
- 电机方向反了？对调 AO1/AO2（或 BO1/BO2）两根线即可

💡 建议的上电顺序：① 先接电池 → MP1584 → 万用表确认 OUT 输出约 5V（定压版，只验证不调）
② 接 ESP32 + I²C 传感器（不接电机/驱动），跑 I²C 扫描
③ 确认传感器都识别后，接 DRV8833 控制线（STBY 一定接）
④ 最后接电机动力线，低 PWM 试转

IPQ-2026 · 接线方案 v3.2 · ESP32 + DRV8833 + 2S 7.4V · 已核对厂家资料 · 2026-08-17

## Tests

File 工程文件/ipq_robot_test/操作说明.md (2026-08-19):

# IPQ 机器人全系统测试程序 · 操作说明

对应程序：`ipq_robot_test.ino`（引脚与 wiring-checklist.html v3.3 逐线对应）
硬件：ESP32 DevKit V1 · DRV8833 · JGB37-520B(1:30)×2 · INA226 · IMU(MPU6050/LSM6DS3 自动识别) · microSD

---

## 1. 烧录步骤

1. Arduino IDE 安装好 **esp32 by Espressif Systems** 开发板包（开发板管理器中搜索 esp32 安装第一个，不是 "Arduino ESP32 Boards"）。
2. **工具 → 开发板** 选 **ESP32 Dev Module**，其余选项保持默认。
3. 用 USB 线连接 ESP32，**工具 → 端口** 选对应 COM 口。
4. 点击「上传」。⚠ 如果卡在 `Connecting........_____`：按住板上的 **BOOT** 键不放，点上传，开始写出时松开；若仍失败，**拔掉 microSD 模块再烧**（GPIO2 是启动脚，SD 卡会干扰进烧录模式），烧完再插回。
5. 打开**串口监视器**，波特率设 **115200**。

**不需要安装任何第三方库**——程序只用了核心自带的 Wire / SPI / SD，INA226 和 MPU6050 都是程序内直接寄存器读写。

---

## 2. 上电/复位后会看到什么

串口按顺序输出：

```
===== IPQ 机器人全系统测试 =====
I2C 扫描: 0x40 0x6B
  INA226 (0x40): 在线
  INA226 配置: 成功(16次平均)
  [IMU诊断] 0x6B: WHO_AM_I(0x0F)=0x69
  [IMU诊断] 0x6B 按 LSM6 寄存器试探成功(CTRL回读一致)，静止合加速度 1.02 g ≈1g → 按兼容芯片启用
  IMU: LSM6 系 (0x6B) 初始化成功
SD: 日志写入 /ipq000.csv
编码器: 11 脉冲/圈 × 1:30 = 每圈轮轴 330 个计数(A相上升沿)
===== 命令（串口发送单个字符）===== ...
上电默认电机为滑行断电状态，发 'g' 或 'w' 开始测试。
```

之后每 100ms 打印一行遥测数据（10Hz）。

**检查点：**
- I²C 扫描必须出现 `0x40`（INA226）。IMU 支持 **MPU6050（0x68/0x69）** 和 **LSM6DS3（0x6A/0x6B）** 两种芯片，程序自动识别，`IMU: ... 初始化成功` 那行会显示识别到的型号（本套实测为 LSM6DS3 @0x6B，属正常）。
- SD 行显示文件名说明记录正常；显示"初始化失败"也不影响其它功能（无卡/接触不良/VCC 电压按清单说明②检查）。
- **上电后电机不转是正常的**（安全设计，滑行断电），必须发命令才动。

---

## 3. 串口命令（在串口监视器输入单个字符发送）

| 命令 | 作用 |
|---|---|
| `w` | 前进（当前速度） |
| `s` | 后退 |
| `a` | 原地左转（左轮退、右轮进） |
| `d` | 原地右转 |
| `x` | 刹车（能耗制动，立即停） |
| `c` | 滑行（断电，惯性滑到停） |
| `+` | 速度 +10%（上限 100%） |
| `-` | 速度 −10% |
| `0`~`9` | 直接设定速度 0%~90%（如 `3` = 30%） |
| `g` | 演示序列：前进 2s → 刹车 0.8s → 后退 2s → 刹车 |
| `v8.06` | 设置电池电压替代值（按万用表实测输入；功率按它计算，换新 INA226 模块后自动用实测） |
| `tl1.05` / `tr0.94` | 左/右轮 PWM 微调（校正差速，0.80~1.20；单独的 `t` 仍是遥测开关） |
| `z` | 编码器计数清零 |
| `p` | 立即打印一帧数据（不影响周期遥测） |
| `t` | 开/关周期遥测打印（SD 记录不受影响，一直在写） |
| `h` | 显示帮助 |

上电默认速度 **30%**（对应接线清单"PWM 30% 低速试转"的要求）。

---

## 4. 遥测数据怎么读

串口每行格式：

```
[  12.3s] encL +1234 (+33)  encR  -567 (-12)  rpm L  -12.3 R  -5.6 | bat 7.82V  cur 0.312A  pow 2.44W | acc +0.02 -0.99 +0.05 g  gyr   1.2  -0.5   3.4 dps  28.5C
```

| 字段 | 含义 | 正常参考值 |
|---|---|---|
| `encL/encR` | 左/右轮累计计数（括号内是本周期增量） | 前进时增大；每 330 计数 = 轮轴一圈 |
| `rpm L/R` | 左/右轮轴转速（转/分），带方向 | 空载 30% 大约 ±100~150 |
| `bat` | 电池电压（INA226 母线端） | 2S 满电 8.4V，<6.4V 该充电 |
| `cur` | 电机总电流 | 空转零点几安，顶到 ±0.82 不再涨＝堵转超量程 |
| `pow` | 电机功率 = V×I | — |
| `acc` | 加速度（单位 g） | 静止水平放置约 `0 0 ±1` |
| `gyr` | 角速度（°/s） | 静止时接近 0 |
| `C` | IMU 芯片温度 | 室温~35°C |

**SD 卡记录**：同样的数据每 100ms 追加一行到 `/ipqNNN.csv`（文件名自动递增，不会覆盖旧数据，每秒落盘一次）。断电后取卡插电脑，可直接用 Excel / Python pandas 读取，列名在 CSV 第一行。

---

## 5. 首次测试推荐流程（安全顺序）

1. **架空轮子**（垫起车体，轮子离地），接好电源。
2. 上电 → 确认 I²C 扫描出 0x40、0x68，遥测正常滚动。
3. 静止读数体检：`acc` 第三列 ≈ ±1，`gyr` ≈ 0，`bat` ≈ 电池实际电压。
4. 发 `g` 跑演示序列，观察：
   - 某个轮子转向不对 → 记下是哪个（详见第 6 节方向修正）；
   - 某个轮子 `enc` 计数一直是 0 → 查该编码器 VCC/GND/A/B 四根线；
   - 前进时某侧计数是负的 → 编码器方向反（第 6 节）。
5. 都正常后发 `w` 手动开，用 `+`/`-` 逐步提速；结束发 `x`。
6. 一切正常后再放下地面，低速直线测试，用 `z` 清零后走固定距离核对编码器刻度。

---

## 6. 方向反了怎么改（二选一）

**改接线（推荐，一劳永逸）**：转向反的电机，把 DRV8833 上该电机的两根输出线对调（左电机 = AO1/AO2，右电机 = BO1/BO2）；编码器方向反则对调该电机的 A/B 相两根信号线。

**改软件（免重新接线）**：打开 `.ino`，改文件开头的宏再重新上传：

```cpp
#define MOT_L_INVERT 0   // 'w' 前进时左轮反转 → 改 1
#define MOT_R_INVERT 0   // 'w' 前进时右轮反转 → 改 1
#define ENC_L_INVERT 0   // 前进时左编码器计数变负 → 改 1
#define ENC_R_INVERT 0   // 前进时右编码器计数变负 → 改 1
```

---

## 7. 其它可调参数（文件开头）

```cpp
#define PWM_FREQ_HZ 20000  // 电机 PWM 频率，DRV8833 上限 250kHz
#define TELE_MS      100    // 遥测/记录周期(ms)
#define R_SHUNT      0.1f   // INA226 采样电阻：看板上粗电阻丝印，R100=0.1(默认)
                           //   R010=0.01Ω → 改 0.01；R001=0.001Ω → 改 0.001
#define ENC_PPR      11     // 编码器每转脉冲（JGB37-520B 出厂 11）
#define GEAR_RATIO   30     // 减速比（电机标签 1:30）
```

⚠ 电流读数说明：INA226 分流满量程 ±81.92mV。配常见的 0.1Ω(R100) 分流电阻时，**可测电流上限约 ±0.82A**——正常运行电流足够，堵转电流会被削顶（读数停在 0.82 附近）。这不影响电压/功率趋势判断；若你的板子丝印不是 R100，按上表改 `R_SHUNT`。

---

## 8. 常见问题排查

| 现象 | 排查 |
|---|---|
| 烧录失败 / 卡在 Connecting | 按住 BOOT 键再点上传；拔掉 microSD 模块（GPIO2） |
| I²C 扫描一个地址都没有 | 查 21(SDA)/22(SCL) 是否接反；红轨 3.3V / 蓝轨 GND 是否正常 |
| 有一个地址、缺另一个 | 缺的器件单独查 4 根线（VCC/GND/SDA/SCL）；扫描出 `0x6B` 属正常（LSM6DS3 的地址），程序会自动识别 |
| 电机完全不动、无电流 | DRV8833 的 **STBY 是否接了 3.3V**（清单线 10，悬空芯片不工作）；VM 上量电池电压 |
| 一侧转一侧不转 | 查不转那侧的 IN1/IN2 两根控制线（23/19 或 18/16）和电机两根动力线 |
| 电流读数总是 0 | 电机线必须从 INA226 的 VIN+/VIN− 走（清单线 1/2），接反则读数为负 |
| SD 初始化失败 | 卡是否插反；模块 VCC 电压（清单说明②：有稳压器的板接 5V，直通的接 3.3V）；GPIO2 接触 |
| 数据偶尔跳变 | 电池电压过低或面包板轨道中段断开（清单说明③，用万用表量红轨首尾通断） |

---

*与 wiring-checklist.html v3.1（42 根线版）配套 · 2026-08-15*

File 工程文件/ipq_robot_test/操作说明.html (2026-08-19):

# IPQ 移动机器人 · 全系统测试程序操作说明ipq_robot_test.ino

ESP32 DevKit V1 · DRV8833 · JGB37-520B(1:30)×2 · INA226 · IMU(MPU6050/LSM6 兼容芯片自动识别) · microSD

接线清单 v3.3 固件 已编译验证 · 无需第三方库 更新 2026-08-17

## 速查引脚分配（与 wiring-checklist.html v3.3 一致）

功能 | 信号 | ESP32 引脚 | 备注
电机驱动 → DRV8833 | AIN1 左方向 | GPIO 23 | STBY 已接 3.3V
| AIN2 左 PWM | GPIO 19
| BIN1 右方向 | GPIO 18
| BIN2 右 PWM | GPIO 16
编码器 → ESP32 | 左 A 相 | GPIO 34 | input-only
| 左 B 相 | GPIO 35 | input-only
| 右 A 相 | GPIO 32 | v3.3 由 36 改
| 右 B 相 | GPIO 33 | v3.3 由 39 改
I²C 总线 | SDA | GPIO 21 | INA226=0x40 · IMU=0x6B
| SCL | GPIO 22 | 并联两器件
SPI → microSD | SCK | GPIO 14 | MISO 在 GPIO2（启动脚）：烧录失败先拔 SD
| MOSI | GPIO 15
| MISO | GPIO 2
| CS | GPIO 27

## 1烧录步骤

1. Arduino IDE 安装 esp32 by Espressif Systems 开发板包（开发板管理器搜索 esp32，选 Espressif 那个）。
2. 工具 → 开发板 选 ESP32 Dev Module，其余选项保持默认。
3. USB 线连接 ESP32，工具 → 端口 选对应 COM 口。
4. 点击「上传」。

烧录卡在 Connecting 时：按住板上 BOOT 键再点上传，开始写出时松开；若仍失败，拔掉 microSD 模块再烧（GPIO2 是启动脚），烧完再插回。

不需要安装任何第三方库——程序只用了核心自带的 Wire / SPI / SD，INA226 和 IMU 都是程序内直接寄存器读写。串口监视器波特率设 115200。

## 2上电 / 复位后会看到什么

===== IPQ 机器人全系统测试 =====
I2C 扫描: 0x40 0x6B
  INA226 (0x40): 在线
  INA226 配置: 成功(16次平均)
  [IMU诊断] 0x6B: WHO_AM_I(0x0F)=0x69
  [IMU诊断] 0x6B 按 LSM6 寄存器试探成功(CTRL回读一致)，静止合加速度 1.02 g ≈1g → 按兼容芯片启用
  IMU: LSM6 系 (0x6B) 初始化成功
SD: 日志写入 /ipq000.csv
编码器: 11 脉冲/圈 × 1:30 = 每圈轮轴 330 个计数(A相上升沿)
===== 命令（串口发送单个字符）===== ...
上电默认电机为滑行断电状态，发 'g' 或 'w' 开始测试。

之后每 100ms 打印一行遥测数据（10Hz）。

检查点：
· I²C 扫描必须出现 0x40（INA226）；IMU 支持 MPU6050（0x68/0x69）和 LSM6 系（0x6A/0x6B）以及身份码异常的兼容芯片，自动识别；
· SD 行显示文件名说明记录正常；显示"初始化失败"不影响其它功能；
· 上电后电机不转是正常的（安全设计，滑行断电），必须发命令才动。

## 3串口命令（串口监视器输入单个字符发送）

命令 | 作用
w | 前进（当前速度）
s | 后退
a | 原地左转（左轮退、右轮进）
d | 原地右转
x | 刹车（能耗制动，立即停）
c | 滑行（断电，惯性滑到停）
+ | 速度 +10%（上限 100%）
- | 速度 −10%
0~9 | 直接设定速度 0%~90%（如 3 = 30%）
g | 演示序列：前进 2s → 刹车 0.8s → 后退 2s → 刹车
v8.06 | 设置电池电压替代值（按万用表实测输入；功率按它计算，换新 INA226 模块后自动用实测）
tl1.05 / tr0.94 | 左/右轮 PWM 微调（校正差速，0.80~1.20；单独的 t 仍是遥测开关）
z | 编码器计数清零
p | 立即打印一帧数据（不影响周期遥测）
t | 开/关周期遥测打印（SD 记录不受影响，一直在写）
h | 显示帮助

上电默认速度 30%（对应接线清单"PWM 30% 低速试转"的要求）。

## 4遥测数据怎么读

串口每行格式：

[  12.3s] encL +1234 (+33)  encR  -567 (-12)  rpm L  -12.3 R  -5.6 | bat 7.82V  cur 0.312A  pow 2.44W | acc +0.02 -0.99 +0.05 g  gyr   1.2  -0.5   3.4 dps  28.5C

字段 | 含义 | 正常参考值
encL/encR | 左/右轮累计计数（括号内是本周期增量） | 前进时增大；每 330 计数 = 轮轴一圈
rpm L/R | 左/右轮轴转速（转/分），带方向 | 空载 30% 大约 ±100~150
bat | 电池电压（INA226 母线端） | 2S 满电 8.4V，<6.4V 该充电
cur | 电机总电流 | 空转零点几安，顶到 ±0.82 不再涨＝堵转超量程
pow | 电机功率 = V×I | —
acc | 加速度（单位 g） | 静止水平放置约 0 0 ±1
gyr | 角速度（°/s） | 静止时接近 0
C | IMU 芯片温度 | 室温~35°C

SD 卡记录：同样的数据每 100ms 追加一行到 /ipqNNN.csv（文件名自动递增不覆盖，每秒落盘一次）。断电后取卡插电脑，Excel / Python pandas 直接读，列名在 CSV 第一行。

## 5首次测试推荐流程（安全顺序）

1. 架空轮子（垫起车体，轮子离地），接好电源。
2. 上电 → 确认 I²C 扫描出 0x40、IMU 识别成功，遥测正常滚动。
3. 静止读数体检：acc 第三列 ≈ ±1，gyr ≈ 0，bat ≈ 电池实际电压。
4. 发 g 跑演示序列，观察：
  - 某个轮子转向不对 → 记下是哪个（见第 6 节方向修正）；
  - 某个轮子 enc 计数一直是 0 → 查该编码器 VCC/GND/A/B 四根线；
  - 前进时某侧计数是负的 → 编码器方向反（第 6 节）。
5. 都正常后发 w 手动开，用 +/- 逐步提速；结束发 x。
6. 一切正常后再放下地面，低速直线测试，用 z 清零后走固定距离核对编码器刻度。

## 6方向反了怎么改（二选一）

改接线（推荐，一劳永逸）：转向反的电机，把 DRV8833 上该电机的两根输出线对调（左 = AO1/AO2，右 = BO1/BO2）；编码器方向反则对调该电机的 A/B 相两根信号线。

改软件（免重新接线）：打开 .ino，改文件开头的宏再重新上传：

#define MOT_L_INVERT 0   // 'w' 前进时左轮反转 → 改 1
#define MOT_R_INVERT 0   // 'w' 前进时右轮反转 → 改 1
#define ENC_L_INVERT 0   // 前进时左编码器计数变负 → 改 1
#define ENC_R_INVERT 0   // 前进时右编码器计数变负 → 改 1

## 7其它可调参数（文件开头）

#define PWM_FREQ_HZ 20000  // 电机 PWM 频率，DRV8833 上限 250kHz
#define TELE_MS      100    // 遥测/记录周期(ms)
#define R_SHUNT      0.1f   // INA226 采样电阻：看板上粗电阻丝印，R100=0.1(默认)
                           //   R010=0.01Ω → 改 0.01；R001=0.001Ω → 改 0.001
#define ENC_PPR      11     // 编码器每转脉冲（JGB37-520B 出厂 11）
#define GEAR_RATIO   30     // 减速比（电机标签 1:30）

电流读数说明：INA226 分流满量程 ±81.92mV。配常见的 0.1Ω(R100) 分流电阻时，可测电流上限约 ±0.82A——正常运行电流足够，堵转电流会被削顶（读数停在 0.82 附近）。这不影响电压/功率趋势判断；若板子丝印不是 R100，按上表改 R_SHUNT。

## 8常见问题排查

现象 | 排查
烧录失败 / 卡在 Connecting | 按住 BOOT 键再点上传；拔掉 microSD 模块（GPIO2）
I²C 扫描一个地址都没有 | 查 21(SDA)/22(SCL) 是否接反；红轨 3.3V / 蓝轨 GND 是否正常
有一个地址、缺另一个 | 缺的器件单独查 4 根线（VCC/GND/SDA/SCL）；扫描出 0x6B 属正常（LSM6 系地址），程序自动识别
电机完全不动、无电流 | DRV8833 的 STBY 是否接了 3.3V（悬空芯片不工作）；VM 上量电池电压
一侧转一侧不转 | 查不转那侧的 IN1/IN2 两根控制线（23/19 或 18/16）和电机两根动力线
电流读数总是 0 | 电机线必须从 INA226 的 VIN+/VIN− 走（清单线 1/2），接反则读数为负
SD 初始化失败 | 卡是否插反；模块 VCC 电压（有稳压器的板接 5V，直通的接 3.3V）；CS(27)/MISO(2) 接线
数据偶尔跳变 | 电池电压过低，或面包板轨道中段断开（用万用表量红轨首尾通断）

IPQ-2026 · 与 wiring-checklist.html v3.3 及 ipq_robot_test.ino 配套 · 2026-08-17

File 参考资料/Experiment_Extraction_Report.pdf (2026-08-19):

# EXP

IPQ 研究项目 · 文献实验提取报告

### EXPERIMENT EXTRACTION

# 五篇论文的实验

# 数据 · 方法 · 过程 · 结论

## Experimental Extraction from 5 Papers on PID & S-Curve Motion Control

本报告系统提取 5 篇参考文献中所有实验的：

- 详细实验数据（量化指标）
- 控制变量与自变量设计
- 实验过程（平台 / 步骤 / 工况）
- 实验结论

并附跨论文实验方法对比矩阵。

A Quantitative Comparison of Jerk-Limited S-Curve and PID Control for Smoother and More Energy-Efficient Mobile Robot Motion 2026.07

IPQ 项目 · 文献实验提取报告 | PID & S-Curve Motion Control
5 篇论文实验数据 · 方法 · 过程 · 结论 | 第 2 页

# 文献实验提取报告

本报告对 IPQ 项目引用的 5 篇论文中的全部实验进行系统提取，重点关注四类信息：

- 详细实验数据——所有报告的量化指标（超调、整定时间、误差、振动幅值等）。
- 控制变量（Constants）——实验中保持不变的参数，确保对比公平性。
- 实验过程——平台、模型参数、工况设置、步骤。
- 实验结论——每篇论文从实验中得出的核心发现。

阅读提示：橙色框 = 控制变量；蓝色框 = 自变量；绿色框 = 因变量/测量指标。

5 篇论文覆盖两条技术路线：反馈控制（PID / 模糊 PID，论文 1/2/4）与前馈轨迹规划（S 曲线，论文 3/5）。 下文按论文逐一提取，最后给出跨论文实验方法对比矩阵。

### 01 BLDC 电机 PID 速度控制 Control BLDC Motor Speed using PID Controller

Mahmud et al., IJACSA 11(3), 2020

# 实验概述

自变量（Independent Variable） 控制器类型（3 水平）

- PI 控制器、PID 控制器、模糊逻辑（Fuzzy Logic）控制器——三种控制器横向对比。

控制变量（Constants） （保持不变的实验条件）

- 被控对象：同一三相 BLDC 电机模型（MATLAB/Simulink 实现）
- 参考转速：2500 rpm（恒定预设值）
- 负载条件：空载（no-load）
- 仿真平台：MATLAB/Simulink（同一求解器与步长）
- PID 增益：Kp=100, Ki=0.5, Kd=500（固定，非自整定）
- 供电与拓扑：同一 DC 源 + 三相逆变器 + 霍尔传感器换相逻辑

因变量 / 测量指标（Dependent Variables）

- 整定时间（Settling Time, ms）
- 超调量（Overshoot, %）
- 欠调量（Undershoot, %）
- 转换速率（Slew Rate, ms）
- 预调节（Pre-shoot, %）
- 电磁转矩、定子电流、反电动势的稳定时间

# 实验过程

5 篇论文实验数据 · 方法 · 过程 · 结论 | 第 3 页

## ① 建模

在 MATLAB/Simulink 中搭建三相 BLDC 电机闭环控制系统：参考源 → PID 控制器 → 驱动电路 → 逆变器（ DC→AC）→ 电机，配以霍尔传感器（3 路）反馈转子位置。逆变器采用六开关全桥，由解码器真值表（Table I/II）确定开关序列。

## ② PID 控制器参数

PID 传递函数：

G(s) = Kp + Ki/s + Kd·s = (Kd·s² + Kp·s + Ki)/s U(t) = Kp·e(t) + Ki·∫e(t)dt + Kd·de(t)/dt

控制器 | Kp | Ki | Kd
PID（本文） | 100 | 0.5 | 500

## ③ 测试工况

设定参考转速 2500 rpm、空载，施加阶跃参考输入，记录转速、电磁转矩、三相定子电流、反电动势、霍尔 信号的时域响应。三种控制器在完全相同的电机模型与工况下分别运行。

# 实验数据

表 1-1：三种控制器性能对比（2500 rpm，空载）

性能指标 | PI 控制器 | PID 控制器 | 模糊控制器
整定时间 | 15.20 ms | ≈18 ms | 9.2 ms
超调量 | 32.67% | 0.4% | 30.92%
欠调量 | 1.68% | 1.9% | 3.2%
转换速率 | 621.35 ms | 92.27 ms | 598.15 ms
预调节 | 0.66% | 2.5% | 0.67%

表 1-2：PID 控制器下系统稳定时间

物理量 | 达到稳定的时间
转速 | 约 0.018 s（18 ms）后恒定于 2500 rpm
电磁转矩 | 约 0.030 s 后稳定
三相定子电流 | 约 0.030 s 后稳定
三相反电动势 | 约 0.030 s 后稳定于 ±24 V

# 实验结论

- PID 控制器综合性能最优：超调仅 0.4%（PI 为 32.67%、模糊为 30.92%），转换速率 92.27 ms（PI 为 621.35 ms），欠调与整定均在可接受范围。
- 模糊控制器整定时间最短（9.2 ms），但超调高达 30.92%，综合不如 PID。
- PI 控制器虽上升较快，但超调过大（32.67%）、转换速率慢，不适合 BLDC 高性能场景。

对本研究的实验设计启示：该实验展示了规范的单因子（控制器类型）对照实验设计——对象、参考值、负载、平 台全部固定，仅改变控制器。我们的 PID vs S 曲线对比可沿用此范式：固定机器人/电机模型与任务，仅改变控制

5 篇论文实验数据 · 方法 · 过程 · 结论 | 第 4 页

策略。但其局限是仅空载、仅阶跃参考——未测试变负载与平滑参考，而这恰是本研究要补充的工况。

Mahmud, M., Motakabber, S. M. A., Alam, A. H. M. Z., & Nordin, A. N. (2020). Control BLDC Motor Speed using PID Controller. IJACSA, 11(3), 477–481.

5 篇论文实验数据 · 方法 · 过程 · 结论 | 第 5 页

02 DC 电机 PID 调速 + PWM 斩波 Design and Implementation Speed Control System of DC Motor based on PID

Hammoodi et al., IJPEDS 11(1), 2020

# 实验概述

自变量（Independent Variable） 控制器配置

- 采用单一 PID 控制器（P=4, I=0.01, D=0.5），验证其在负载扰动下的转速维持能力。
- （注：本文为单组验证实验，非多控制器横向对比；对照性体现在施加扰动前/后。）

控制变量（Constants） （保持不变的实验条件）

- 被控对象：他励直流电机（separately excited DC motor），同一参数集
- 电机参数：电橙电阻 R、电感 L、反电动势常数 Kb、转动惯量 J、粘性摩擦 b
- 拓扑：DC 源 → GTO-1 晶闸管斩波电路 → DC 电机
- 控制器：PID（P=4, I=0.01, D=0.5），固定不整定
- 平台：MATLAB/Simulink（同一模型）

因变量 / 测量指标（Dependent Variables）

- 实际转速 wr 相对参考转速的跟踪（时域响应曲线）
- 负载转矩 TL 的动态响应
- 电橙电流 Ia 的动态响应
- GTO-1 晶闸管的 PWM 触发信号

# 实验过程

## ① DC 电机建模

电机分为电气部分（电橙：R、L、反电动势 Kb）与机械部分（转子：惯量 J、摩擦系数 b、转矩 T、角速度 ω） 。关键方程：

V_dc = E_am + I_am·R_a + V_brush ; E_am = K_m·I_f·ω ; T = K_m·I_a·I_f

## ② 斩波驱动电路

采用 GTO-1 晶闸管 + 续流二极管构成斩波电路（chopper）。GTO-1 模型为三端开关：中间为控制端，控制信 号为 1 时输出 DC 电压，为 0 时输出零。通过 PWM 信号控制其通断，调节电橙平均电压，进而调节转速。

## ③ 闭环控制

转速闭环：测量实际转速 → 与参考转速（常数）比较 → PID 输出 → 确定参考电橙电流 → 驱动斩波器。系统 机械负载由惯量 J、摩擦 B、负载转矩 TL 表征。

## ④ PID 参数

5 篇论文实验数据 · 方法 · 过程 · 结论 | 第 6 页
参数 | 值
P（比例） | 4
I（积分） | 0.01
D（微分） | 0.5

# 实验数据

论文以 Simulink 仿真波形（Figure 6–9）形式给出结果，关键观察如下（定性 + 半定量）：

图号 | 物理量 | 实验观察
Fig. 6 | 实际转速 wr | PID 控制下快速跟踪参考转速，响应迅速
Fig. 7 | 负载转矩 TL | 展现快速响应，扰动下能恢复
Fig. 8 | 电橙电流 Ia | 快速响应，与转矩同步
Fig. 9 | PWM 信号（GTO-1） | 给出晶闸管触发波形，形成完整斩波链路

数据说明：论文未在正文给出精确数值表格，结果主要以 Simulink 波形图呈现。核心定量结论为：PID 控制下系统对参考转速与负载扰动均表现出快速响应。

# 实验结论

- PID 控制器能在负载扰动（disturbances）下自动维持转速恒定，验证了闭环 PID + PWM 斩波方案的有效 性。
- 不同厂商的 PID 算法实现存在差异，更换控制器时必须重新计算参数才能达到期望动态行为。
- 所提方法经济可行、易于实现，可移植到任意 DC 电机。

对本研究的实验设计启示：本文展示了扰动响应实验范式——在系统稳态后施加负载扰动，观察恢复能力。这对我 们评估 S 曲线 + PID 在移动机器人遇到外部阻力（如爬坡、负载变化）时的鲁棒性有直接参考价值。但其局限明显 ：仅定性、无量化对比、无能耗数据、无平滑性指标——这些都是本研究需要补充的测量维度。

Hammoodi, S. J., Flayyih, K. S., & Hamad, A. R. (2020). Design and implementation speed control system of DC Motor based on PID control and Matlab Simulink. IJPEDS, 11(1), 127–134.

5 篇论文实验数据 · 方法 · 过程 · 结论 | 第 7 页

### 03 S 曲线运动轨迹优化（最小残余振动） Optimized S-Curve Motion Profiles for Minimum Residual Vibration

Meckl, Arestides & Woods, ACC 1998

# 实验概述

本文实验为仿真实验（无硬件），但实验设计极为严谨——是 5 篇中控制变量设计最规范的一篇。核心对比： 三种输入力函数（轨迹类型）在相同柔性系统下产生的残余振动。

自变量（Independent Variable） 输入轨迹类型（3 水平，核心自变量）

- 梯形速度轨迹（Trapezoid）：ta* = 0，即矩形力脉冲
- 经验 S 曲线（S-Curve）：ta* = 1/6（工程经验法则）
- 优化 S 曲线（Optimal S）：ta* 按 ωn·tr/2π 关系最优选取

控制变量（Constants） （保持不变的实验条件）

- 系统模型：同一双质量（two-mass）柔性系统（m1, m2, k）
- 名义自然频率 ωn = √(k·(m1+m2)/(m1·m2))
- 阻尼：分析阶段为无阻尼；点对点仿真阶段加 ζ = 0.05 轻阻尼
- 峰值力 Fmax、总质量 mtotal、峰值速度 vp（同一组）
- 巡航（coast）时间：ωn·td/2π = 10（所有点对点仿真一致）

因变量 / 测量指标（Dependent Variables）

- 无量纲残余加速度幅值 a*（dB）——残余振动的量化指标
- 在不同 ωn·tr/2π（无量纲响应时间）下的 a* 曲线

# 实验过程

## ① 系统建模

采用双质量弹簧系统模拟柔性机构（如机械臂、定位台）。适用于阻尼比 ζ < 0.1 的轻阻尼系统（大多数实际系 统如此）。传递函数 X2(s)/F(s) 含一个振动模态。

## ② 频域分析（核心方法）

推导出 S 曲线力输入产生的无量纲残余加速度 a* 的解析表达式：

a* = f(ta*, ωn·tr/2π) —— 残余振动是“上升时间 ta*”与“无量纲响应时间 ωn·tr/2π”的函数

绘制 a* 随 ta* 变化曲线，发现存在使 a* 极小的下凹点（dip）。选取最小下凹点对应的 ta*，即可同时最小化 响应时间与残余振动。

## ③ 鲁棒性设计（关键控制变量引入）

引入第二个自变量——自然频率不确定性：分两种场景评估：

- 理想场景：实际频率 = 名义频率（ωa = ωn）

5 篇论文实验数据 · 方法 · 过程 · 结论 | 第 8 页
- 失配场景：实际频率比名义高 10%（ωa = 1.1·ωn），模拟模型不确定性

## ④ 实验执行

对三种轨迹 × 两种频率场景 = 6 组仿真，在 ωn·tr/2π = 1~10 范围内扫描，记录每组残余加速度曲线（Fig. 6–9）。

# 实验数据

表 3-1：三种轨迹在两种频率场景下的残余振动对比（a*, dB）

场景 | 梯形 (ta*=0) | 经验 S (ta*=1/6) | 优化 S 曲线 | 改善幅度
理想（ωa=ωn） | 基准（最高） | 多数情况改善 | 全范围最低 | 显著
频率偏差 10% | 残余振动大 | 改善有限 | 仍显著最低 | 低 ωn·tr/2π 区 ≈ 20 dB

表 3-2：关键实验参数汇总

参数 | 值 / 设置 | 说明
系统模型 | 双质量 + 弹簧 | 单振动模态柔性系统
阻尼比 ζ | 0.05（仿真阶段） | 轻阻尼，模拟实际机构
巡航时间 ωn·td/2π | 10 | 所有点对点仿真固定
频率失配 | 0% 与 +10% | 理想 vs 鲁棒性测试
ωn·tr/2π 扫描范围 | 1 ~ 10 | 覆盖慢柔性到快刚性
优化点选取 | ta*=0.332 @ ωn·tr/2π=2 | 取整数点后的下一个下凹点

# 实验结论

- 优化 S 曲线在全范围最优：无论理想还是频率失配场景，优化 S 曲线的残余振动均最低。
- 改善近一个数量级：相对非优化输入，残余振动降低接近 10 倍（≈ 20 dB）。
- 对频率不确定性鲁棒：即使实际频率偏差 10%，优化 S 曲线仍显著优于梯形与经验 S 曲线。
- 改善在低 ωn·tr/2π 区最显著——即低自然频率或极快运动场景，这正是减振最困难的工况。

对本研究的实验设计启示（极高价值）：本文提供了 S 曲线实验的黄金范式：①固定系统模型，仅变轨迹类型（单 因子对照）；②引入频率失配作为鲁棒性测试维度；③用无量纲指标 a* 使结论可推广。我们的实验可直接借鉴：固定移动机器人模型，对比 PID vs S 曲线，并用负载/惯量失配作为鲁棒性维度。其残余振动指标 a* 可对应我们的平滑性指标（jerk 峰值、加速度连续性）。

Meckl, P. H., Arestides, P. B., & Woods, M. C. (1998). Optimized S-curve motion profiles for minimum residual vibration. Proc. ACC, Philadelphia, pp. 2627–2631.

5 篇论文实验数据 · 方法 · 过程 · 结论 | 第 9 页

### 04 模糊自整定 PID 直流电机调速 Speed Control of DC Motor Using Fuzzy PID Controller

Bansal & Narvey, AEEE 3(9), 2013

# 实验概述

自变量（Independent Variable） 控制器类型（2 水平，核心自变量）

- 传统定参 PID（Conventional PID）：增益固定不变
- 模糊自整定 PID（Fuzzy Self-Tuning PID）：增益由模糊逻辑在线调整

控制变量（Constants） （保持不变的实验条件）

- 被控对象：同一 DC 电机模型（参数见下表）
- 电机参数：Ra=0.5Ω, La=0.02H, Va=200V, Jm=0.1 kg·m², Bm=0.008 N·m·s/rad, K=1.25, 额定 1500 rpm
- 参考转速：157.07 rad/s（对应 1500 rpm）
- 仿真平台：MATLAB/Simulink（Fuzzy 工具箱）
- 模糊控制器结构（固定）：双输入（e, de）× 三输出（Kp, Ki, Kd），三角隶属函数，25 条规则

因变量 / 测量指标（Dependent Variables）

- 动态响应：上升时间 Tr
- 整定时间（Settling Time）
- 最大超调 Mp（%）
- 稳态误差 SSE
- 误差 e 与误差变化率 de 的时域曲线

# 实验过程

## ① DC 电机建模

建立电橙电压方程与转矩平衡方程，拉氏变换后简化（电气时间常数 Ta ≪ 机电时间常数 Tem）：

ω(s)/Va(s) = (1/Km) / [(1+s·Tem)(1+s·Ta)]

电机参数（Table 1）：

参数 | 值 | 参数 | 值
电橙电阻 Ra | 0.5 Ω | 机械惯量 Jm | 0.1 kg·m²
电橙电感 La | 0.02 H | 摩擦系数 Bm | 0.008 N·m·s/rad
电橙电压 Va | 200 V | 反电动势常数 K | 1.25 V·s/rad
额定转速 | 1500 rpm | 转矩常数 | 1 N·m/A

## ② 模糊控制器设计

5 篇论文实验数据 · 方法 · 过程 · 结论 | 第 10 页

结构：双输入（转速误差 eω、误差变化率 deω）→ 三输出（Kp, Ki, Kd）。

模糊化：三角隶属函数，7 档（NL/NM/NS/ZE/PS/PM/PL），零点附近加密以提高稳态精度。

规则库：每个增益 25 条规则（5×5），形如：

IF (eω is NL) AND (deω is NL) THEN (Kp is PV)

推理：Max-product；解模糊：将模糊输出还原为精确的 Kp/Ki/Kd 值。

## ③ 自整定原理

核心是找出 PID 三参数与 (e, de) 的模糊关系，在不同误差状态下实时修改增益——稳态附近细化（高精度）， 远离零点处展宽（快响应）。

## ④ 对比实验

在同一电机模型、同一参考转速下，分别运行传统 PID 与模糊自整定 PID，记录并对比时域响应指标。

# 实验数据

论文以 Simulink 仿真波形（Fig. 6–7）呈现，核心对比结论如下：

性能维度 | 传统定参 PID | 模糊自整定 PID | 优劣
动态响应 | 一般 | 更好 | 模糊优于传统
上升时间 Tr | 较长 | 更短 | 模糊优于传统
整定时间 | 较长 | 更短 | 模糊优于传统
最大超调 Mp | 较大 | 更小 | 模糊优于传统
稳态误差 SSE | 较大 | 更小，精度更高 | 模糊优于传统

数据说明：论文未在正文给出精确数值表，结果以传统 vs 模糊的波形对比（Fig. 6 转速、Fig. 7 误差）定性呈现，所有维度均为模糊自整定 PID 占优。

# 实验结论

- 模糊自整定 PID 全面优于传统 PID：动态响应更好、上升/整定时间更短、超调更小、稳态精度更高。
- 模糊自整定 PID 同时具备 PID 的精确性与模糊控制的灵活性。
- 在瞬态与稳态两方面均优于传统 PID，实现完美速度跟踪。

对本研究的实验设计启示：本文提供了强化 baseline思路——若我们仅对比定参 PID vs S 曲线，可能被质疑 PID 调得不够好。引入模糊自整定 PID 作为更强的反馈控制对照组，可使 S 曲线在平滑性/能耗上的优势结论更有说服力。但需注意：模糊 PID 仍是反馈范式，无法解决阶跃参考本身的 jerk 问题——这恰是 S 曲线（前馈规划）的不可替代价值。本实验无能耗数据、无 jerk 指标，是我们需要补充的。

Bansal, U. K., & Narvey, R. (2013). Speed Control of DC Motor Using Fuzzy PID Controller. Advance in Electronic and Electric Engineering, 3(9), 1209–1220.

5 篇论文实验数据 · 方法 · 过程 · 结论 | 第 11 页

### 05 S 曲线运动轨迹规划算法（含硬件实测） On Algorithms for Planning S-curve Motion Profiles

Nguyen, Ng & Chen, IJARS 5(1), 2008

# 实验概述

本文是 5 篇中唯一含真实硬件实验的论文。核心对比：不同阶数/类型的 S 曲线模型在同一直线电机上产生的 运动质量。

自变量（Independent Variable） S 曲线模型类型与阶数（核心自变量）

- 多项式 S 曲线：3 阶、4 阶、5 阶（jerk 分别为矩形脉冲/连续/高阶光滑）
- 三角 jerk 模型（Trigonometric）：用 sin 函数替代矩形 jerk 脉冲

控制变量（Constants） （保持不变的实验条件）

- 硬件平台：同一直线电机系统（气浮导轨，低摩擦）
- 控制器：PMDi MC4000 Pro 八轴 PCI DSP 运动控制卡
- 反馈：Renishaw 激光传感器 RLD + 激光编码器 RLU10（四相信号）
- 约束：峰值速度 60 mm/s，峰值位置 50 mm
- 算法：同一时间最优规划算法（仅模型阶数/类型不同）

因变量 / 测量指标（Dependent Variables）

- 速度轨迹的光滑度（时域波形）
- 位置误差（Position Error）——核心精度指标
- 峰值约束是否被违反（速度/位置）

# 实验过程

## ① 硬件平台

直线电机在气浮轴承上滑动，实现超精密、低摩擦、安静运动。由 PMDi MC4000 Pro 控制卡驱动；用户通过 PMDi GUI（C 语言 + LabWindows/CVI）交互。

## ② 算法（被测对象）

多项式 S 曲线递推广义模型：以位置最高阶导数（模板）为起点，逐次积分得到 jerk/加速度/速度/位置。各阶 段数 = 2（n=阶数）：

模型 | 阶数 n | 轨迹段数 2ⁿ | jerk 特性
梯形速度 | 2 | 4 | 无穷大（跳变）
3 阶多项式 S | 3 | 8 | 有限（矩形脉冲）
4 阶多项式 S | 4 | 16 | 连续
n 阶多项式 S | n | 2 | 更高阶光滑

5 篇论文实验数据 · 方法 · 过程 · 结论 | 第 12 页

时间最优规划算法：给定各阶峰值上限，迭代求解常数输入段时间 Tp，确保无峰值违反且时间最优。

三角 jerk 模型：7 段轨迹，用 sin 函数替换 3 阶模型的矩形 jerk 脉冲，使 jerk 绝对光滑。

## ③ 实验执行

算法生成数值数组形式的路径点 → 下载至 PMDi 控制卡 → 控制器指挥直线电机执行 S 曲线轨迹。对 3/4/5 阶 多项式模型 + 三角模型分别实测，记录速度与位置误差。

# 实验数据

表 5-1：各模型运动质量对比（同一硬件）

模型 | 速度/位置光滑度 | 峰值约束 | 位置误差
3 阶多项式 | 光滑 | 未违反（60mm/s, 50mm） | 最大
4 阶多项式 | 光滑 | 未违反 | 中等（居中）
5 阶多项式 | 更光滑 | 未违反 | 最小
三角模型 | 光滑（jerk 绝对光滑） | 未违反 | ≈ 5 阶多项式水平

关键定量约束（峰值）：速度 ≤ 60 mm/s，位置 ≤ 50 mm——所有模型均未违反。

核心趋势：模型阶数 3 → 4 → 5，位置误差递减（Fig. 8）。三角模型虽简单如 3 阶，位置误差却接近 5 阶多项 式（Fig. 10）。

# 实验结论

- 阶数越高，性能越好：3 → 4 → 5 阶多项式 S 曲线，位置误差依次降低。
- 三角模型性价比最高：复杂度仅相当于 3 阶，性能却媲美 5 阶多项式——因两者的 jerk 均光滑，一阶导 数仅在连接时刻有尖锐边。
- 算法保证峰值不越限：所有模型在 60 mm/s 速度、50 mm 位置约束下均未违反。
- 能耗展望：论文在结论中明确指出未来将评估所规划轨迹的能耗，并合理推测光滑且 jerk 有界的运动可 最优地节省能量。

对本研究的实验设计启示（最相关）：本文是本研究 S 曲线算法的直接来源，也是唯一含硬件实测的参考。其固定 硬件、变模型阶数的单因子对照范式、以及位置误差作为精度指标的做法，可直接迁移到我们的移动机器人实验。 更重要的是，论文明确把能耗评估与移动机器人扩展列为未来工作——这正是本研究的核心命题。我们可引用此文 作为 S 曲线节能假设的理论依据，并用实验验证该假设。

Nguyen, K. D., Ng, T.-C., & Chen, I.-M. (2008). On Algorithms for Planning S-curve Motion Profiles. International Journal of Advanced Robotic Systems, 5(1), 99–106.

5 篇论文实验数据 · 方法 · 过程 · 结论 | 第 13 页

# 跨论文实验方法对比矩阵

下表横向对比 5 篇论文的实验设计要素，便于识别本研究可借鉴与需补充之处。

## 实验基本要素

论文 | 实验类型 | 平台 | 被控/测试对象 | 对照组数
01 BLDC PID | 仿真 | MATLAB/Simulink | 三相 BLDC 电机 | 3（PI/PID/Fuzzy）
02 DC PID | 仿真 | MATLAB/Simulink | 他励 DC 电机 | 1（仅 PID，扰动前后）
03 Meckl S | 仿真 | 解析 + 数值仿真 | 双质量柔性系统 | 3（Trap/S/Opt-S）× 2 频率
04 Fuzzy PID | 仿真 | MATLAB/Simulink | DC 电机 | 2（传统/模糊 PID）
05 Nguyen S | 硬件+仿真 | 直线电机+PMDi | 直线电机（气浮） | 4（3/4/5阶+三角）

## 控制变量与自变量设计

论文 | 核心自变量 | 关键控制变量 | 鲁棒性测试维度
01 | 控制器类型 | 电机/参考2500rpm/空载/PID增益 | 无
02 | 扰动施加 | 电机/PID参数/拓扑 | 无（仅扰动响应）
03 | 轨迹类型 + ta* | 系统模型/coast时间/peak力 | 频率失配±10%
04 | 控制器类型 | 电机/参考1500rpm/模糊结构 | 无
05 | S曲线阶数/模型 | 硬件/峰值约束/算法 | 无（仅模型对比）

## 测量指标覆盖度

指标 | 01 BLDC | 02 DC | 03 Meckl | 04 Fuzzy | 05 Nguyen
超调/整定时间 | ✓ | △ | — | ✓ | —
位置误差 | — | — | — | — | ✓
残余振动 | — | — | ✓ | — | —
扰动响应 | — | ✓ | — | — | —
jerk / 平滑性 | — | — | △(隐含) | — | △(隐含)
能耗 | （缺失） | | | | （待评估）
量化数据表 | ✓ | △(波形) | ✓ | △(波形) | ✓

✓ = 明确给出；△ = 部分提及/仅波形；— = 未涉及； = 缺失。关键发现：5 篇论文无一测量能耗，仅论文 3 涉及振动/平滑性的量化。这为本研究的能耗 + 平滑性双维度量化提供了明确的差异化空间。

## 对本研究的综合实验设计建议

- 借鉴论文 1/4 的对照范式：固定机器人模型与任务，仅变控制策略（定参 PID / 模糊 PID / S 曲线 / S 曲线 +PID）。
- 借鉴论文 3 的鲁棒性维度：引入负载/惯量失配（如 ±10~20%）作为鲁棒性测试，增强结论说服力。

5 篇论文实验数据 · 方法 · 过程 · 结论 | 第 14 页
- 借鉴论文 5 的硬件验证：在仿真之外，争取在真实移动机器人平台上验证，提升研究可信度。
- 填补共同空白——能耗：5 篇均无能耗数据。测量 S 曲线 vs PID 的电流/功率积分，是本研究最具差异化 的贡献。
- 补充 jerk 量化：5 篇仅论文 3 隐含涉及振动。显式测量jerk 峰值与 RMS作为平滑性指标。

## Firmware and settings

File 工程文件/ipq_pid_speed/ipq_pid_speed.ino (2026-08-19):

/*
 * =====================================================================
 *  IPQ 研究 · 双电机差速的 PID 抑制
 * =====================================================================
 *  目标：左右轮各自用编码器测速，经 PID 闭环跟踪同一目标转速，
 *        消除开环 PWM 下 ~5% 量级的轮速差（电机/摩擦个体差异）。
 *
 *  硬件与接线：与 ipq_robot_test 完全相同（wiring-checklist v3.3）
 *  依赖库：无（仅 ESP32 核心自带 Wire / SPI / SD）
 *
 *  研究用法：
 *   1. 'w' 起步后按 'o' 切换 开环↔闭环，观察 Δrpm 与 gyrZ 的变化；
 *   2. 串口改 kp/ki/kd/ff 参数做调参实验（掉电丢失，记到本子上）；
 *   3. 'z' 清零编码器后 'w' 跑 5 秒 'x'，得到阶跃响应曲线（SD 有完整记录）；
 *   4. ff 设为 0 可对比"纯 PID"与"前馈+PID"的收敛速度。
 *
 *  串口命令（115200）：
 *    w/s/a/d 前进/后退/左转/右转   x 刹车   c 滑行   z 编码器清零
 *    0~9 目标转速 = 数字×15 rpm（3 → 45）  + / - 目标 ±5 rpm
 *    r60     直接设目标转速(rpm)
 *    kp2.0 / ki0.1 / kd0.05 / ff1.3   改 PID 参数（如 ki0 = 关积分）
 *    o       开环 / 闭环 切换（研究对照用）
 *    p 立即打印一帧   t 遥测开关   e 串口CSV输出   v8.06 电池电压替代值   h 帮助
 * =====================================================================
 */

#include <Wire.h>
#include <SPI.h>
#include <SD.h>

/* ---------------- 引脚（wiring-checklist v3.3）---------------- */
static const uint8_t PIN_AIN1    = 23;   // 左电机 方向
static const uint8_t PIN_AIN2    = 19;   // 左电机 PWM
static const uint8_t PIN_BIN1    = 18;   // 右电机 方向
static const uint8_t PIN_BIN2    = 16;   // 右电机 PWM
static const uint8_t PIN_ENC_LA  = 34;
static const uint8_t PIN_ENC_LB  = 35;
static const uint8_t PIN_ENC_RA  = 32;
static const uint8_t PIN_ENC_RB  = 33;
static const uint8_t PIN_SDA     = 21;
static const uint8_t PIN_SCL     = 22;
static const uint8_t PIN_SD_SCK  = 14;
static const uint8_t PIN_SD_MOSI = 15;
static const uint8_t PIN_SD_MISO = 2;
static const uint8_t PIN_SD_CS   = 27;

static const uint8_t ADDR_INA = 0x40;

static const char CSV_HEADER[] = "ms,tgt,rpmL,rpmR,pwmL,pwmR,gyrZ,busV,curA,powW";

/* ---------------- 可调参数 ---------------- */
#define PWM_FREQ_HZ   20000
#define R_SHUNT       0.1f    // INA226 采样电阻（丝印 R100=0.1Ω）
#define ENC_PPR       11      // JGB37-520B 编码器 PPR
#define GEAR_RATIO    30      // 减速比 1:30 → 轮轴 330 计数/圈
#define ENC_L_INVERT  0       // 前进时左计数为负 → 改 1
#define ENC_R_INVERT  0
#define MOT_L_INVERT  0       // 'w' 时左轮反转 → 改 1
#define MOT_R_INVERT  0
#define TSAMP_MS      100     // 控制周期 100ms（转速量化 ≈1.8rpm，勿太短）
#define RPM_FILT_A    0.35f   // 转速低通系数（0~1，越小越平滑越迟钝）
#define I_MAX         120.0f  // 积分限幅（抗饱和，PWM 当量）

/* ---------------- PID 状态（串口随时改）---------------- */
static float kp = 2.0f;       // 比例：1 rpm 误差 → 几个 PWM 当量
static float ki = 0.15f;      // 积分
static float kd = 0.0f;       // 微分（默认关；量化噪声大，慎用）
static float ff = 1.3f;       // 前馈：PWM/rpm（0 = 纯 PID）
static float targetRpm = 45;  // 目标转速（幅值）
static bool  pidOn = true;    // false = 开环（两轮同 PWM，对照组）

/* =====================================================================
 *  LEDC PWM 封装（兼容核心 2.x / 3.x）
 * ===================================================================== */
#if defined(ESP_ARDUINO_VERSION) && ESP_ARDUINO_VERSION >= ESP_ARDUINO_VERSION_VAL(3, 0, 0)
static void pwmSetup(uint8_t pin)            { ledcAttach(pin, PWM_FREQ_HZ, 8); }
static void pwmWrite(uint8_t pin, uint32_t d){ ledcWrite(pin, d); }
#else
static uint8_t pwmChOf(uint8_t pin) { return (pin == PIN_AIN2) ? 0 : 1; }
static void pwmSetup(uint8_t pin)   { ledcSetup(pwmChOf(pin), PWM_FREQ_HZ, 8); ledcAttachPin(pin, pwmChOf(pin)); }
static void pwmWrite(uint8_t pin, uint32_t d) { ledcWrite(pwmChOf(pin), d); }
#endif

/* =====================================================================
 *  DRV8833：IN1=方向(数字)、IN2=PWM（与接线清单 E/F 组一致）
 * ===================================================================== */
static void motorWrite(uint8_t dirPin, uint8_t pwmPin, int speed)
{
  if (speed > 0) {
    digitalWrite(dirPin, HIGH);
    pwmWrite(pwmPin, 255 - speed);
  } else if (speed < 0) {
    digitalWrite(dirPin, LOW);
    pwmWrite(pwmPin, (uint32_t)(-speed));
  } else {
    digitalWrite(dirPin, LOW);
    pwmWrite(pwmPin, 0);
  }
}

static void setMotors(int l, int r)
{
#if MOT_L_INVERT
  l = -l;
#endif
#if MOT_R_INVERT
  r = -r;
#endif
  motorWrite(PIN_AIN1, PIN_AIN2, l);
  motorWrite(PIN_BIN1, PIN_BIN2, r);
}

static void brakeAll()
{
  digitalWrite(PIN_AIN1, HIGH); pwmWrite(PIN_AIN2, 255);
  digitalWrite(PIN_BIN1, HIGH); pwmWrite(PIN_BIN2, 255);
}

/* ---------------- 运动指令状态 ---------------- */
static int8_t dirL = 0, dirR = 0;    // -1/0/+1，来自 w/s/a/d

/* =====================================================================
 *  编码器
 * ===================================================================== */
static volatile int32_t encCountL = 0;
static volatile int32_t encCountR = 0;

void IRAM_ATTR isrEncL() { digitalRead(PIN_ENC_LB) ? encCountL++ : encCountL--; }
void IRAM_ATTR isrEncR() { digitalRead(PIN_ENC_RB) ? encCountR++ : encCountR--; }

/* =====================================================================
 *  I²C 读写 + INA226（电流/电压；母线通道坏则电压用替代值）
 * ===================================================================== */
static bool    inaOK = false;
static uint32_t inaRetryAt = 0;
static float   vBatFallback = 8.0f;

static bool i2cWrite8(uint8_t addr, uint8_t reg, uint8_t val)
{
  Wire.beginTransmission(addr);
  Wire.write(reg); Wire.write(val);
  return Wire.endTransmission() == 0;
}

static bool i2cWrite16(uint8_t addr, uint8_t reg, uint16_t val)
{
  Wire.beginTransmission(addr);
  Wire.write(reg); Wire.write(val >> 8); Wire.write(val & 0xFF);
  return Wire.endTransmission() == 0;
}

static int16_t i2cRead16(uint8_t addr, uint8_t reg, bool &ok)
{
  Wire.beginTransmission(addr); Wire.write(reg);
  if (Wire.endTransmission(false) != 0) { ok = false; return 0; }
  if (Wire.requestFrom((uint8_t)addr, (uint8_t)2) != 2)         { ok = false; return 0; }
  uint16_t v = ((uint16_t)Wire.read() << 8) | Wire.read();
  ok = true;
  return (int16_t)v;
}

static bool i2cRead8(uint8_t addr, uint8_t reg, uint8_t &out)
{
  Wire.beginTransmission(addr); Wire.write(reg);
  if (Wire.endTransmission(false) != 0) return false;
  if (Wire.requestFrom((uint8_t)addr, (uint8_t)1) != 1) return false;
  out = Wire.read();
  return true;
}

static bool inaInit()
{
  bool ok = i2cWrite16(ADDR_INA, 0x00, 0x4587);   // 16 次平均，分流+母线连续
  bool okR;
  uint16_t cfg = (uint16_t)i2cRead16(ADDR_INA, 0x00, okR);
  Serial.printf("  [INA诊断] CFG回读=0x%04X %s\n", cfg, ok ? "OK" : "失败");
  return ok;
}

/* =====================================================================
 *  IMU（MPU6050 / LSM6 兼容自动识别）+ 陀螺零偏
 * ===================================================================== */
static bool    imuOK    = false;
static bool    imuIsLSM = false;
static uint8_t imuAddr  = 0;
static float   gyroBias[3] = {0, 0, 0};

static bool imuRead(int16_t a[3], int16_t &tRaw, int16_t g[3]);   // 前置声明

static bool imuInit()
{
  uint8_t v;
  for (uint8_t a = 0x6A; a <= 0x6B; a++) {          // LSM6 系（WHO_AM_I=0x0F）
    if (!i2cRead8(a, 0x0F, v)) continue;
    if (v == 0x6A || v == 0x6B || v == 0x6C) {
      imuAddr = a; imuIsLSM = true;
      bool ok = i2cWrite8(a, 0x12, 0x44);
      ok &= i2cWrite8(a, 0x10, 0x40);               // 104Hz ±2g
      ok &= i2cWrite8(a, 0x11, 0x40);               // 104Hz ±245dps
      delay(50);
      return ok;
    }
  }
  for (uint8_t a = 0x68; a <= 0x69; a++) {          // MPU6050（WHO_AM_I=0x75）
    if (!i2cRead8(a, 0x75, v) || v != 0x68) continue;
    imuAddr = a; imuIsLSM = false;
    bool ok = i2cWrite8(a, 0x6B, 0x01);
    ok &= i2cWrite8(a, 0x19, 0x04);
    ok &= i2cWrite8(a, 0x1A, 0x03);
    ok &= i2cWrite8(a, 0x1B, 0x00);
    ok &= i2cWrite8(a, 0x1C, 0x00);
    delay(50);
    return ok;
  }
  for (uint8_t a = 0x6A; a <= 0x6B; a++) {          // 兼容片盲试探：写 CTRL3_C 回读验证
    Wire.beginTransmission(a);
    if (Wire.endTransmission() != 0) continue;
    if (!i2cWrite8(a, 0x12, 0x44)) continue;
    uint8_t rb = 0;
    if (!i2cRead8(a, 0x12, rb) || rb != 0x44) continue;
    i2cWrite8(a, 0x10, 0x40);
    i2cWrite8(a, 0x11, 0x40);
    delay(60);
    imuAddr = a; imuIsLSM = true;
    return true;
  }
  return false;
}

static bool imuRead(int16_t a[3], int16_t &tRaw, int16_t g[3])
{
  Wire.beginTransmission(imuAddr);
  if (imuIsLSM) Wire.write(0x22);
  else          Wire.write(0x3B);
  if (Wire.endTransmission(false) != 0) return false;
  uint8_t n = imuIsLSM ? 12 : 14;
  if (Wire.requestFrom((uint8_t)imuAddr, n) != n) return false;
  if (imuIsLSM) {
    for (int i = 0; i < 3; i++)
      g[i] = (int16_t)((uint16_t)Wire.read() | ((uint16_t)Wire.read() << 8));
    for (int i = 0; i < 3; i++)
      a[i] = (int16_t)((uint16_t)Wire.read() | ((uint16_t)Wire.read() << 8));
    Wire.beginTransmission(imuAddr); Wire.write(0x20);
    if (Wire.endTransmission(false) != 0) return false;
    if (Wire.requestFrom((uint8_t)imuAddr, (uint8_t)2) != 2) return false;
    uint8_t lo = Wire.read(), hi = Wire.read();
    tRaw = (int16_t)((uint16_t)lo | ((uint16_t)hi << 8));
  } else {
    for (int i = 0; i < 3; i++)
      a[i] = ((int16_t)Wire.read() << 8) | Wire.read();
    tRaw = ((int16_t)Wire.read() << 8) | Wire.read();
    for (int i = 0; i < 3; i++)
      g[i] = ((int16_t)Wire.read() << 8) | Wire.read();
  }
  return true;
}

/* =====================================================================
 *  microSD：研究数据记录
 * ===================================================================== */
static File logFile;
static bool sdOK = false;
static uint8_t flushCnt = 0;

static void sdInit()
{
  SPI.begin(PIN_SD_SCK, PIN_SD_MISO, PIN_SD_MOSI, PIN_SD_CS);
  if (!SD.begin(PIN_SD_CS)) {
    Serial.println(F("SD 卡初始化失败（不影响其它功能；烧录时建议拔下 SD 模块）"));
    return;
  }
  char name[20];
  for (int i = 0; i < 1000; i++) {
    snprintf(name, sizeof(name), "/pid%03d.csv", i);
    if (!SD.exists(name)) break;
  }
  logFile = SD.open(name, FILE_WRITE);
  if (!logFile) { Serial.println(F("SD 卡无法创建日志文件")); return; }
  logFile.println(CSV_HEADER);
  logFile.flush();
  sdOK = true;
  Serial.printf("SD: 日志写入 %s\n", name);
}

/* =====================================================================
 *  速度测量 + 双轮 PID
 * ===================================================================== */
static int32_t lastCntL = 0, lastCntR = 0;
static float   rpmL = 0, rpmR = 0;          // 低通后转速（带符号）
static float   iL = 0, iR = 0;              // 积分累加
static float   prevL = 0, prevR = 0;        // 上拍转速（微分用）
static float   uL = 0, uR = 0;              // 本拍 PWM 输出（带符号）
static float   gyrZ = 0;                    // 陀螺 Z 轴（转向角速度）
static float   vBus = NAN, iMot = NAN, pMot = NAN;
static bool    vAssumed = false;
static bool    telemetryOn = true;
static bool    csvOut = false;        // e 命令：把 CSV 数据行同步输出到串口（无 SD 卡时用电脑记录）

static void resetPid()
{
  iL = iR = 0;
  prevL = rpmL;  prevR = rpmR;
}

/* 单轮 PID：返回带符号 PWM(-255..255)。T=带符号目标转速 */
static float pidStep(float T, float rpm, float &integ, float &prev)
{
  if (T == 0) { integ = 0; return 0; }
  float e  = T - rpm;
  float dt = TSAMP_MS / 1000.0f;
  float p  = kp * e;
  integ += ki * e * dt;                            // 积分
  if (integ >  I_MAX) integ =  I_MAX;              // 抗饱和
  if (integ < -I_MAX) integ = -I_MAX;
  float d  = -kd * (rpm - prev) / dt;              // 微分作用于测量值（避免目标阶跃踢）
  prev = rpm;
  float u = ff * T + p + integ + d;                // 前馈 + PID
  if (u >  255) u =  255;
  if (u < -255) u = -255;
  return u;
}

static void controlStep()
{
  /* --- 1. 转速测量（编码器差分 + 低通）--- */
  int32_t l = encCountL, r = encCountR;
  float dL = (float)(l - lastCntL);  lastCntL = l;
  float dR = (float)(r - lastCntR);  lastCntR = r;
  float k  = 60000.0f / TSAMP_MS / (ENC_PPR * GEAR_RATIO);
  float rawL = dL * k * (ENC_L_INVERT ? -1 : 1);
  float rawR = dR * k * (ENC_R_INVERT ? -1 : 1);
  rpmL += RPM_FILT_A * (rawL - rpmL);
  rpmR += RPM_FILT_A * (rawR - rpmR);

  /* --- 2. 传感器（陀螺 Z 轴 = 差速效果的独立判据；INA 供电参数）--- */
  int16_t a3[3], tRaw, g3[3];
  if (imuOK && imuRead(a3, tRaw, g3))
    gyrZ = (g3[2] - gyroBias[2]) * (imuIsLSM ? 8.75f / 1000 : 1.0f / 131.0f);
  else
    imuOK = false;

  if (!inaOK && inaRetryAt && (int32_t)(millis() - inaRetryAt) >= 0) {
    inaRetryAt = 0;
    if (i2cWrite16(ADDR_INA, 0x00, 0x4587)) { inaOK = true; Serial.println(F("!! INA226 已重新上线")); }
    else inaRetryAt = millis() + 10000;
  }
  if (inaOK) {
    bool ok;
    int16_t shunt = i2cRead16(ADDR_INA, 0x01, ok);
    if (!ok) { inaOK = false; inaRetryAt = millis() + 10000; }
    else     { iMot = (shunt * 2.5e-6f) / R_SHUNT; }
    int16_t bus = i2cRead16(ADDR_INA, 0x02, ok);
    if (ok) {
      vBus = bus * 0.00125f;
      vAssumed = (vBus < 0.5f);
      if (vAssumed) vBus = vBatFallback;
      pMot = vBus * iMot;
    } else if (!inaOK) { vBus = iMot = pMot = NAN; }
  }

  /* --- 3. 双轮控制 --- */
  float TL = dirL * targetRpm;
  float TR = dirR * targetRpm;
  if (pidOn) {
    uL = pidStep(TL, rpmL, iL, prevL);
    uR = pidStep(TR, rpmR, iR, prevR);
  } else {                                  // 开环对照：两轮同 PWM
    uL = ff * TL;  if (uL >  255) uL =  255;  if (uL < -255) uL = -255;
    uR = ff * TR;  if (uR >  255) uR =  255;  if (uR < -255) uR = -255;
  }
  if (dirL == 0 && dirR == 0) return;       // 停止状态保持刹车/滑行
  setMotors((int)uL, (int)uR);
}

/* ---------------- 遥测与记录 ---------------- */
static void printTelemetry()
{
  Serial.printf("[%6.1fs] %s T%+5.1f | L %5.1frpm u%+4.0f  R %5.1frpm u%+4.0f | d%+5.1frpm gyrZ %+5.1f | ",
                millis() / 1000.0, pidOn ? "PID" : "开环", targetRpm,
                rpmL, uL, rpmR, uR, rpmL - rpmR, gyrZ);
  if (!isnan(vBus))
    Serial.printf("bat %.2f%sV cur %.3fA pow %.2fW\n", vBus, vAssumed ? "*" : "", iMot, pMot);
  else
    Serial.println(F("bat  ----   cur  ----   pow  ----"));
}

static void appF(char *line, float v)
{
  char c[24];
  if (isnan(v)) strcat(line, ",");
  else { snprintf(c, sizeof(c), ",%.4f", v); strcat(line, c); }
}

static void buildCsvLine(char *line, size_t n)
{
  snprintf(line, n, "%lu", (unsigned long)millis());
  appF(line, targetRpm); appF(line, rpmL); appF(line, rpmR);
  appF(line, uL);        appF(line, uR);   appF(line, gyrZ);
  appF(line, vBus);      appF(line, iMot); appF(line, pMot);
  strcat(line, "\n");
}

static void logSample()
{
  char line[200];
  buildCsvLine(line, sizeof(line));
  logFile.print(line);
  if (++flushCnt >= 10) { flushCnt = 0; logFile.flush(); }
}

/* =====================================================================
 *  串口命令
 * ===================================================================== */
static void printHelp()
{
  Serial.println(F("\n===== PID 差速抑制 · 命令 ====="));
  Serial.println(F("  w 前进   s 后退   a 左转   d 右转   x 刹车   c 滑行"));
  Serial.printf (F("  0~9 目标=数字×15rpm(3→45)  + / - 目标±5rpm（当前 %.0f）\n"), targetRpm);
  Serial.println(F("  r60 设目标 | o 开环/闭环切换 | z 编码器清零"));
  Serial.printf (F("  kp%.2f ki%.2f kd%.2f ff%.2f  → 串口如 kp3.0 直接改\n"), kp, ki, kd, ff);
  Serial.println(F("  p 打印一帧   t 遥测开关   e 串口CSV输出   v8.06 电池电压   h 帮助"));
  Serial.println(F("研究建议：起步→'o'来回切换看 d(rpm)/gyrZ 变化；z→w→5s→x 得阶跃响应"));
}

static void setDir(int8_t dl, int8_t dr, const char *name)
{
  dirL = dl; dirR = dr;
  resetPid();
  if (dl == 0 && dr == 0) { brakeAll(); Serial.printf("-> %s（已刹车）\n", name); }
  else                    { Serial.printf("-> %s 目标 %.0frpm\n", name, targetRpm); }
}

static void handleChar(char c)
{
  if (c == '\r' || c == '\n') return;
  switch (c) {
    case 'w': setDir(+1, +1, "前进"); break;
    case 's': setDir(-1, -1, "后退"); break;
    case 'a': setDir(-1, +1, "原地左转"); break;
    case 'd': setDir(+1, -1, "原地右转"); break;
    case 'x': setDir(0, 0, "刹车"); break;
    case 'c': dirL = dirR = 0; setMotors(0, 0); resetPid(); Serial.println(F("-> 滑行断电")); break;
    case 'o': pidOn = !pidOn; resetPid();
              Serial.printf("-> %s模式\n", pidOn ? "PID 闭环" : "开环（同 PWM 对照）"); break;
    case 'z': encCountL = 0; encCountR = 0; lastCntL = 0; lastCntR = 0;
              Serial.println(F("-> 编码器已清零")); break;
    case 'p': printTelemetry(); break;
    case 'e': csvOut = !csvOut;       // e = export（原用 l，与数字 1 形近易误触，已改）
              if (csvOut) Serial.println(CSV_HEADER);
              Serial.printf("-> 串口 CSV 输出 %s（用电脑记录这些数据行）\n", csvOut ? "开" : "关");
              break;
    case 't': telemetryOn = !telemetryOn; Serial.printf("-> 遥测 %s\n", telemetryOn ? "开" : "关"); break;
    case 'h': printHelp(); break;
    default:
      if (c >= '0' && c <= '9') {
        targetRpm = (c - '0') * 15;
        Serial.printf("-> 目标 %.0f rpm\n", targetRpm);
      } else if (c == '+' || c == '=') {
        targetRpm = min(150.0f, targetRpm + 5); Serial.printf("-> 目标 %.0f rpm\n", targetRpm);
      } else if (c == '-' || c == '_') {
        targetRpm = max(0.0f, targetRpm - 5); Serial.printf("-> 目标 %.0f rpm\n", targetRpm);
      } else {
        Serial.printf("未知命令 '%c'（h 查看帮助）\n", c);
      }
      break;
  }
}

static void handleLine(char *line)
{
  struct { const char *cmd; float *val; float lo, hi; const char *name; } P[] = {
    { "kp", &kp, 0,  50, "Kp" },
    { "ki", &ki, 0,  10, "Ki" },
    { "kd", &kd, 0,  10, "Kd" },
    { "ff", &ff, 0,   3, "前馈" },
    { "r",  &targetRpm, 10, 150, "目标转速" },
  };
  for (auto &p : P) {
    size_t n = strlen(p.cmd);
    if (strncasecmp(line, p.cmd, n) == 0 && line[n] != '\0') {
      float v = atof(line + n);
      if (v >= p.lo && v <= p.hi) {
        *p.val = v;
        Serial.printf("-> %s = %.3f（目标 %.0frpm, kp%.2f ki%.2f kd%.2f ff%.2f）\n",
                      p.name, v, targetRpm, kp, ki, kd, ff);
      } else {
        Serial.printf("格式: %s数值（范围 %.0f~%.0f）\n", p.cmd, p.lo, p.hi);
      }
      return;
    }
  }
  if ((line[0] == 'v' || line[0] == 'V') && line[1] != '\0') {
    float v = atof(line + 1);
    if (v >= 5.0f && v <= 9.0f) { vBatFallback = v; Serial.printf("-> 电池电压替代值 = %.2fV\n", vBatFallback); }
    else Serial.println(F("格式: v8.06（5~9V）"));
    return;
  }
  for (char *q = line; *q; q++) handleChar(*q);
}

/* =====================================================================
 *  Setup / Loop
 * ===================================================================== */
static void i2cScan()
{
  Serial.print(F("I2C 扫描:"));
  uint8_t n = 0;
  for (uint8_t a = 1; a < 127; a++) {
    Wire.beginTransmission(a);
    if (Wire.endTransmission() == 0) {
      Serial.printf(" 0x%02X", a); n++;
      if (a == ADDR_INA) inaOK = true;
    }
  }
  if (n == 0) Serial.print(F(" （未发现器件）"));
  Serial.println();
}

void setup()
{
  Serial.begin(115200);
  delay(300);
  Serial.println(F("\n===== IPQ · 双电机差速 PID 抑制 ====="));

  pinMode(PIN_AIN1, OUTPUT);  digitalWrite(PIN_AIN1, LOW);
  pinMode(PIN_AIN2, OUTPUT);  digitalWrite(PIN_AIN2, LOW);
  pinMode(PIN_BIN1, OUTPUT);  digitalWrite(PIN_BIN1, LOW);
  pinMode(PIN_BIN2, OUTPUT);  digitalWrite(PIN_BIN2, LOW);
  pwmSetup(PIN_AIN2);
  pwmSetup(PIN_BIN2);
  pwmWrite(PIN_AIN2, 0);
  pwmWrite(PIN_BIN2, 0);

  pinMode(PIN_ENC_LA, INPUT);  pinMode(PIN_ENC_LB, INPUT);
  pinMode(PIN_ENC_RA, INPUT);  pinMode(PIN_ENC_RB, INPUT);
  attachInterrupt(digitalPinToInterrupt(PIN_ENC_LA), isrEncL, RISING);
  attachInterrupt(digitalPinToInterrupt(PIN_ENC_RA), isrEncR, RISING);

  Wire.begin(PIN_SDA, PIN_SCL);
  Wire.setTimeout(50);
  i2cScan();
  if (inaOK) { inaOK = inaInit(); }
  if (!inaOK) inaRetryAt = millis() + 10000;

  imuOK = imuInit();
  if (imuOK) Serial.printf("  IMU: %s (0x%02X) 初始化成功\n", imuIsLSM ? "LSM6 系" : "MPU6050", imuAddr);
  else       Serial.println(F("  IMU: 未识别到（gyrZ 将不可用）"));
  if (imuOK) {                                 // 陀螺零偏校准：上电保持静止
    Serial.print(F("  IMU 陀螺零偏校准中（保持静止）…"));
    int16_t a[3], t, g[3];
    long acc[3] = {0, 0, 0};
    int n = 0;
    uint32_t t0 = millis();
    while (n < 200 && millis() - t0 < 1000) {
      if (imuRead(a, t, g)) { acc[0] += g[0]; acc[1] += g[1]; acc[2] += g[2]; n++; }
      delay(2);
    }
    if (n > 0) {
      gyroBias[0] = acc[0] / (float)n; gyroBias[1] = acc[1] / (float)n; gyroBias[2] = acc[2] / (float)n;
      Serial.printf("完成（Z 轴 %.1f dps）\n", gyroBias[2] * (imuIsLSM ? 8.75f / 1000 : 1.0f / 131.0f));
    } else Serial.println(F("失败"));
  }

  sdInit();
  printHelp();
  Serial.println(F("上电默认：PID 闭环、目标 45rpm、kp2.0 ki0.15 kd0 ff1.3"));
}

void loop()
{
  /* 行命令缓冲（同测试程序） */
  static char     lineBuf[16];
  static uint8_t  lineLen = 0;
  static uint32_t lastCharMs = 0;
  while (Serial.available()) {
    char c = (char)Serial.read();
    lastCharMs = millis();
    if (c == '\r' || c == '\n') {
      if (lineLen > 0) { lineBuf[lineLen] = 0; handleLine(lineBuf); lineLen = 0; }
    } else if (lineLen < sizeof(lineBuf) - 1) {
      lineBuf[lineLen++] = c;
    }
  }
  if (lineLen > 0 && millis() - lastCharMs > 50) {
    lineBuf[lineLen] = 0; handleLine(lineBuf); lineLen = 0;
  }

  static uint32_t tCtrl = 0;
  uint32_t now = millis();
  if (now - tCtrl >= TSAMP_MS) {
    tCtrl = now;
    controlStep();
    if (telemetryOn) printTelemetry();
    if (sdOK)        logSample();
    if (csvOut)    { char line[200]; buildCsvLine(line, sizeof(line)); Serial.print(line); }
  }
}

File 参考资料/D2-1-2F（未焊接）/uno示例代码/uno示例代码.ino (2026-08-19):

// 定义电机控制引脚
#define ENA 5   // 电机1 PWM调速引脚（必须支持PWM）
#define IN1 6   // 电机1方向引脚1
#define IN2 7   // 电机1方向引脚2
#define ENB 10  // 电机2 PWM调速引脚
#define IN3 8   // 电机2方向引脚1
#define IN4 9   // 电机2方向引脚2

void setup() {
  // 初始化所有引脚为输出
  pinMode(ENA, OUTPUT);
  pinMode(IN1, OUTPUT);
  pinMode(IN2, OUTPUT);
  pinMode(ENB, OUTPUT);
  pinMode(IN3, OUTPUT);
  pinMode(IN4, OUTPUT);
  
  Serial.begin(9600);
  Serial.println("UNO两路电机控制示例");
}

void loop() {
  // 示例动作：电机1正转，电机2反转，然后停止
  setMotor(1, 255, true);  // 电机1全速正转
  setMotor(2, 150, false); // 电机2半速反转
  delay(2000);

  stopMotor(1);            // 停止电机1
  stopMotor(2);            // 停止电机2
  delay(1000);
}

/**
 * 控制指定电机运动
 * @param motor 电机编号（1或2）
 * @param speed 速度（0-255）
 * @param forward 方向（true=正转，false=反转）
 */
void setMotor(int motor, int speed, bool forward) {
  if (motor == 1) {
    analogWrite(ENA, speed);               // 设置电机1速度+
    digitalWrite(IN1, forward ? HIGH : LOW);
    digitalWrite(IN2, forward ? LOW : HIGH);
  } else if (motor == 2) {
    analogWrite(ENB, speed);               // 设置电机2速度
    digitalWrite(IN3, forward ? HIGH : LOW);
    digitalWrite(IN4, forward ? LOW : HIGH);
  }
}

/**
 * 停止指定电机
 */
void stopMotor(int motor) {
  if (motor == 1) {
    digitalWrite(IN1, LOW);
    digitalWrite(IN2, LOW);
    analogWrite(ENA, 0);
  } else if (motor == 2) {
    digitalWrite(IN3, LOW);
    digitalWrite(IN4, LOW);
    analogWrite(ENB, 0);
  }
}

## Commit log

2026-08-19 Add PID serial logger, experiment logs, guides, and PPF draft
2026-08-21 整理仓库：按工程文件/答辩/参考资料/参考文献分类，新增 README
    - 新增 4 个分类目录，文件夹整体移动（保留 git 历史）
    - 新增 README.md：项目简介、目录结构、分类说明、文档再生成方法
    - 修正 gen_experiments.py / gen_summaries.py 中硬编码的 D:/IPQ 路径和
    Windows 字体路径，改为相对路径 + 跨平台字体候选
    - 教材 PDF 重命名为简洁文件名；删除 Thumbs.db 并加入 .gitignore
    [i2c_identify.ino, ipq_pid_speed.ino, ipq_robot_test.ino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]
2026-08-21 移动 DRV8833 驱动板资料（D2-1-2F）到 参考资料，同步更新 README
2026-08-21 新增面包板→PCB 载板工程：Gerber 生成器、原理图、装配与下单说明
    [IPQ-CARRIER_V1-NPTH.drl, IPQ-CARRIER_V1-PTH.drl, IPQ-CARRIER_V1.GBL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]
2026-08-21 修复底层预览图镜像：改为与顶层同视角（与嘉立创在线预览一致）
2026-08-22 新增开题答辩 PPT 与大纲
